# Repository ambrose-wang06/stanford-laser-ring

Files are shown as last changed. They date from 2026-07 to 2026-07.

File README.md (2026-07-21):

# Stanford Laser Ring

Real-Time Laser Collision Visualization System — Department of Radiation Oncology, Stanford University.

This repository contains the STL files needed to 3D print the laser ring, the wiring/assembly reference, and the Arduino code used to run the system.

> Developed by Ambrose Wang, Piotr Dubrowski, Aisha Burns, Amy Yu, and Lawrie Skinner — Department of Radiation Oncology, Stanford University, Palo Alto, CA.

## Overview

The laser ring is an isometric ring of 40 laser diodes (5V, 650nm, 5mW) that forms a visible boundary around the linac gantry to help radiation therapists spot potential collisions between the patient/immobilization devices and the gantry or on-board imaging system — without needing a manual dry run.

The 40 diodes are split into **8 independently controlled segments** (5 diodes each). If a segment's beam is broken by the patient or equipment, therapists get an immediate visual cue. The system can also flash a specific segment based on predicted collisions coming from the treatment planning system.

## Bill of Materials

### 3D Printed Parts

| Part | Quantity |
|---|---|
| `control_box_back_bracket_left` | 1 |
| `control_box_back_bracket_right` | 1 |
| `control_box_bottom` | 1 |
| `control_box_top` | 1 |
| `control_box_connector_left` | 1 |
| `control_box_connector_right` | 1 |
| `diode_ball_joint` | 40 |
| `laser_ring_back_bracket` | 7 |
| `laser_ring_segment_bottom` | 8 |
| `laser_ring_segment_top` | 8 |

All parts were designed in Onshape and printed in PLA on a Prusa i3 MK3 for structural rigidity. STL files are in the [`/STL`](./STL) folder.

### Other Materials

| Item | Quantity | Notes |
|---|---|---|
| Laser diodes (5V, 650nm, 5mW) | 40 | 5 per segment, 8 segments |
| Arduino (microcontroller) | 1 | Controls the 8 segments independently |
| Wiring | — | Each group of 8 diodes wired in its own parallel branch for independent segment control and easy fault isolation |
| Screws (ball-joint reinforcement) | — | Secures each diode's alignment after calibration |
| Remote sensor / power switch | 1 | Mounts through the aperture in the control box for remote on/off |

## Assembly

1. **Print all parts** listed in the Bill of Materials above using the STL files in this repo.
2. **Assemble the ring**: mount each laser diode into a `diode_ball_joint`, then secure the ball joints into the `laser_ring_segment_top`/`laser_ring_segment_bottom` pairs to build all 8 segments.
3. **Join the segments**: connect adjacent segments using the `laser_ring_back_bracket` pieces (7 total) to form the full ring.
4. **Build the control box**: assemble `control_box_top`, `control_box_bottom`, and the left/right back brackets and connectors around the Arduino and wiring.
5. **Wire the diodes**: wire each segment's 5 diodes in their own parallel branch back to the control box, so each segment can be individually controlled and faulty diodes can be isolated without affecting other segments.
6. **Mount the remote sensor** through the aperture in the upper-left corner of the control box for power on/off.
7. **Mount the assembled ring** vertically on the wall facing the linac, with the beams projected horizontally toward the gantry.

## Calibration / QA

1. Mount the calibration ring on the gantry head, parallel to the laser ring.
2. Power on the system and check that each laser beam passes through its corresponding aperture on the calibration ring.
3. For any diode off by more than 2 mm at the calibration ring, use the adjustment screw on that diode's ball-joint housing to re-align it until the beam passes through its aperture.
4. Repeat daily until stability is established; the system can move to monthly QA checks once alignment drift is confirmed to stay under 1 mm over time.

## Software

The predictive warning system has **three parts** that hand data off to each other in sequence:

1. **`RingCollisionDetection_Script/`** — an Eclipse Scripting API (ESAPI) plugin that runs *inside Varian Eclipse*. When run against an open plan, it checks the patient's BODY/EXTERNAL/SUPPORT structures against the linac geometry, works out which of the 8 laser segments (if any) are predicted to collide, and writes the result to a shared JSON file named `{MRN}.json`.
2. **`RingCollCommunicator/`** — a Windows console app (.NET) that runs on the PC connected to the Arduino via USB. It auto-detects the Arduino's COM port, looks up which patient is currently "In Progress" on the treatment machine in ARIA, reads that patient's `{MRN}.json` file, and sends the list of colliding segment numbers to the Arduino over serial.
3. **`Arduino Code/SerialOnly_5_29_2026/`** — the sketch that runs on the Arduino itself, described below.

### How a treatment session runs

1. Therapist points an IR remote at the ring and presses the power button.
2. The Arduino turns **all 8 segments on solid** and sends `ReadyForSegments` over serial.
3. The Communicator app receives that, looks up the in-progress patient in ARIA, reads their collision JSON, and sends back either `CLEAR` (no predicted collisions — lasers stay solid) or a comma-separated list of segment numbers (e.g. `3,4`).
4. The Arduino sets those specific segments to **blink** while the rest stay solid, giving the therapist a location-specific warning.
5. Pressing the IR remote again turns everything off.

### Setup

**1. Eclipse Scripting API script**
- Add `RingCollisionDetection.cs` and `CollisonDetection.cs` to your Eclipse Scripting API project (references `VMS.TPS.Common.Model.API`, `Newtonsoft.Json`) and get it approved/verified per your institution's Eclipse scripting workflow.
- Set the shared `FolderPath` in `CollisionFileWriter` (top of `RingCollisionDetection.cs`) to the network location the Communicator app will also read from.

**2. RingCollCommunicator (PC app)**
- Requires **Newtonsoft.Json**, **System.Management**, and your institution's ARIA connectivity library (referenced as `RingAriaQ` / `RingAria` — not included in this repo; link against your own ARIA API library).
- Set `machineId` in `Program.cs` to the treatment machine's ID in ARIA.
- Set `FolderPath` in `CollisionFileReader` to the **same** shared folder used by the Eclipse script above.
- Build and run this app on the PC that's plugged into the Arduino via USB. It will wait until it detects an Arduino, then listen continuously.

**3. Arduino**
- Install the [Arduino IDE](https://www.arduino.cc/en/software) and the **IRremote** library (`IRremote.hpp`, by Armin Joachimsmeyer — install via Library Manager).
- Open `Arduino Code/SerialOnly_5_29_2026/SerialOnly_5_29_2026.ino`.
- Under **Tools > Board**, select your board; under **Tools > Port**, select the Arduino's port.
- Click **Upload**.
- Connect an IR receiver to pin 14, and the 8 segment relay lines to the pins listed in `relayPins[]` in the sketch.

### ⚠️ Known issues to resolve before deployment

- **`FolderPath` is a placeholder (redacted) in both `RingCollisionDetection.cs` and `Program.cs`.** These must be filled in with a real, matching path before the two apps can hand off data.
- **`machineId` in `Program.cs` is also a placeholder** — set this to your treatment machine's actual ARIA ID.
- **`Program.cs` references a variable `inProgressLA2Pt`** when logging the "in-progress patient found" message, but the variable that's actually populated is `inProgressPt`. As written, this will not compile — needs a fix (likely just renaming to `inProgressPt`).
- **Relay pins 0 and 1 are used as digital outputs** in the Arduino sketch (`relayPins[] = {5, 4, 3, 2, 1, 0, A6, A5}`), but pins 0/1 are the hardware Serial RX/TX lines on most Arduino boards. Since this sketch also uses `Serial` for communication with the Communicator app, double-check this doesn't cause conflicts on your specific board.

## Repository Structure

```
├── STL/                                    # 3D printable parts (see Bill of Materials)
├── RingCollisionDetection_Script/          # Eclipse Scripting API plugin (runs in Varian Eclipse)
│   ├── RingCollisionDetection.cs
│   └── CollisonDetection.cs
├── RingCollCommunicator/                   # Windows console app — bridges Eclipse/ARIA data to the Arduino
│   └── Program.cs
├── Arduino Code/
│   └── SerialOnly_5_29_2026/
│       └── SerialOnly_5_29_2026.ino        # Arduino sketch — relay/segment control + IR power toggle
└── README.md
```

## Contact

Questions about this project can be directed to the Stanford Radiation Oncology team.

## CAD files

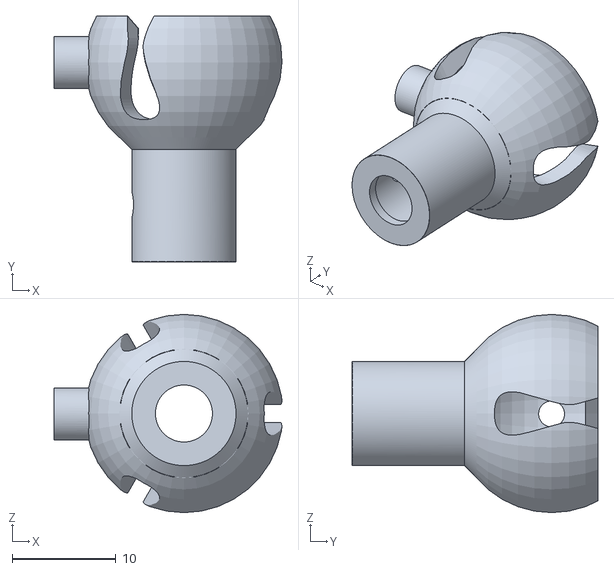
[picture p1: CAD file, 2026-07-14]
laser_ring_stl/diode_ball_joint.stl
22.0 x 23.7 x 19.2

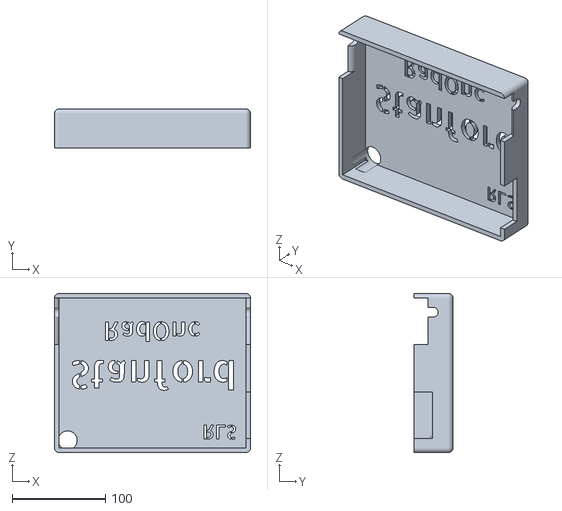
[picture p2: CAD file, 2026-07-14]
laser_ring_stl/control_box_top.stl
210.4 x 42.0 x 170.9

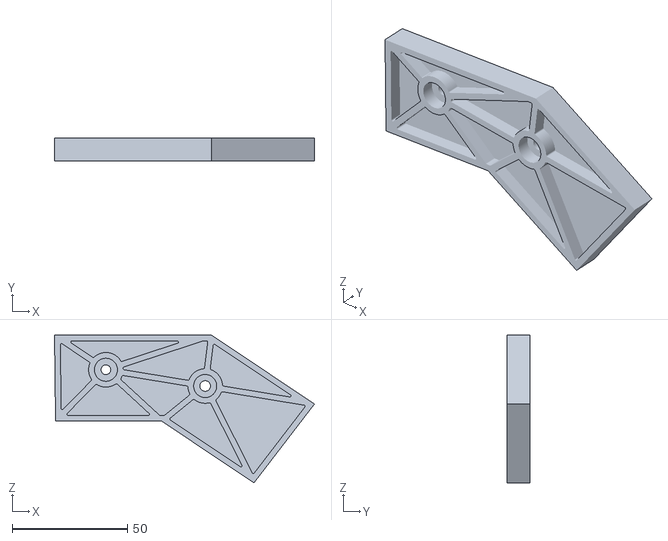
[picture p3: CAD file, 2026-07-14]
laser_ring_stl/control_box_back_bracket_right.stl
112.7 x 10.0 x 64.0

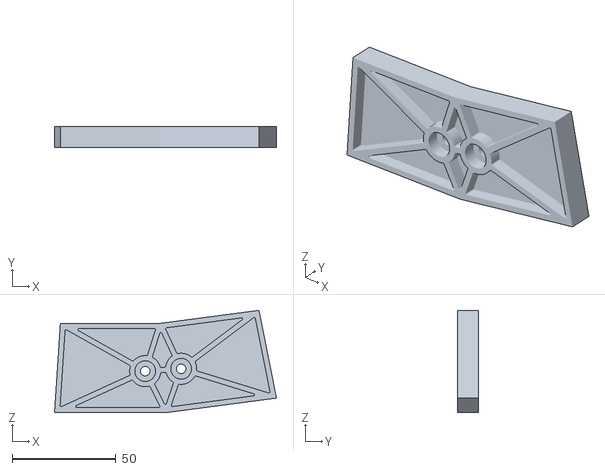
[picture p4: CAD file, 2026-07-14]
laser_ring_stl/laser_ring_back_bracket.stl
107.0 x 10.0 x 49.3

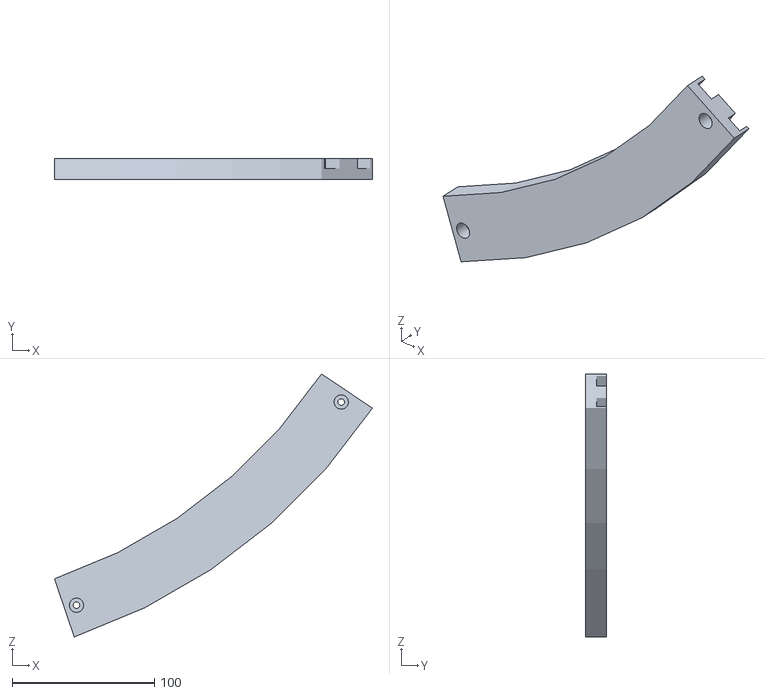
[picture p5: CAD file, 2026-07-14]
laser_ring_stl/laser_ring_segment_bottom.stl
223.3 x 14.5 x 184.6

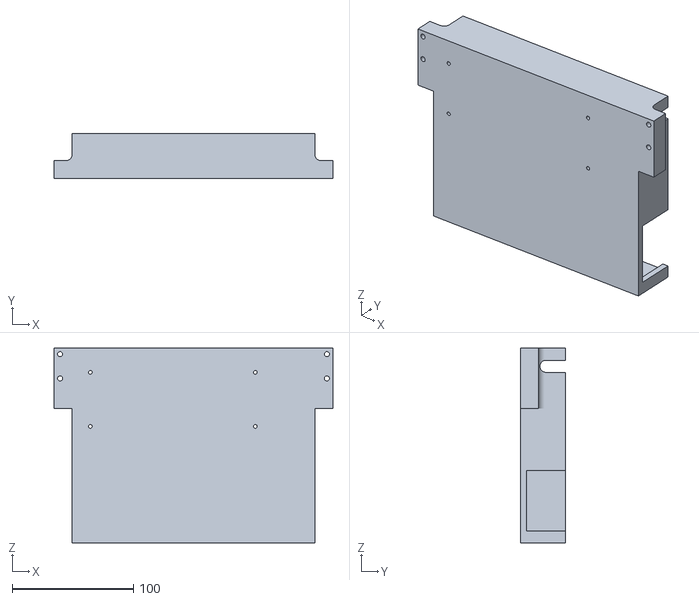
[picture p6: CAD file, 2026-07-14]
laser_ring_stl/control_box_bottom.stl
230.0 x 37.0 x 160.5

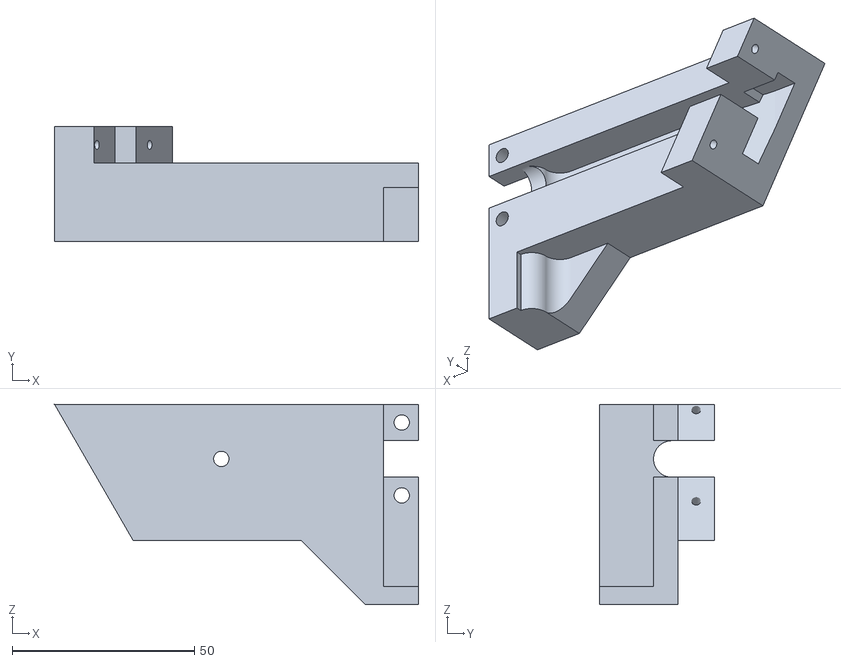
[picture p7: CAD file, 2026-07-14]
laser_ring_stl/control_box_connector_left.stl
99.9 x 31.5 x 55.0

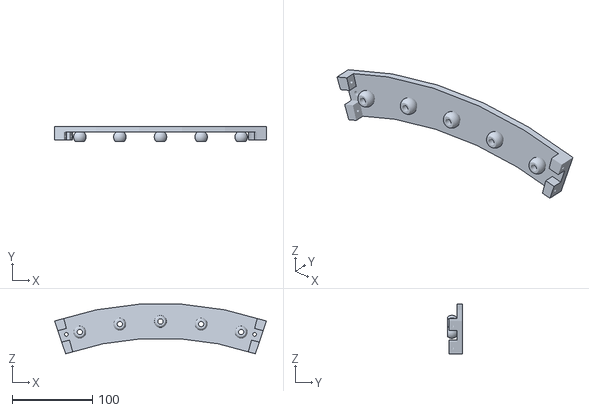
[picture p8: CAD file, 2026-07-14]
laser_ring_stl/laser_ring_segment_top.stl
264.0 x 18.7 x 61.7

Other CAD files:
laser_ring_stl/control_box_back_bracket_left.stl
laser_ring_stl/control_box_connector_right.stl
